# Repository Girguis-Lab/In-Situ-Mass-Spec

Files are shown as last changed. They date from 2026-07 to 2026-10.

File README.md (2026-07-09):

# In-Situ Mass Spectrometer V3

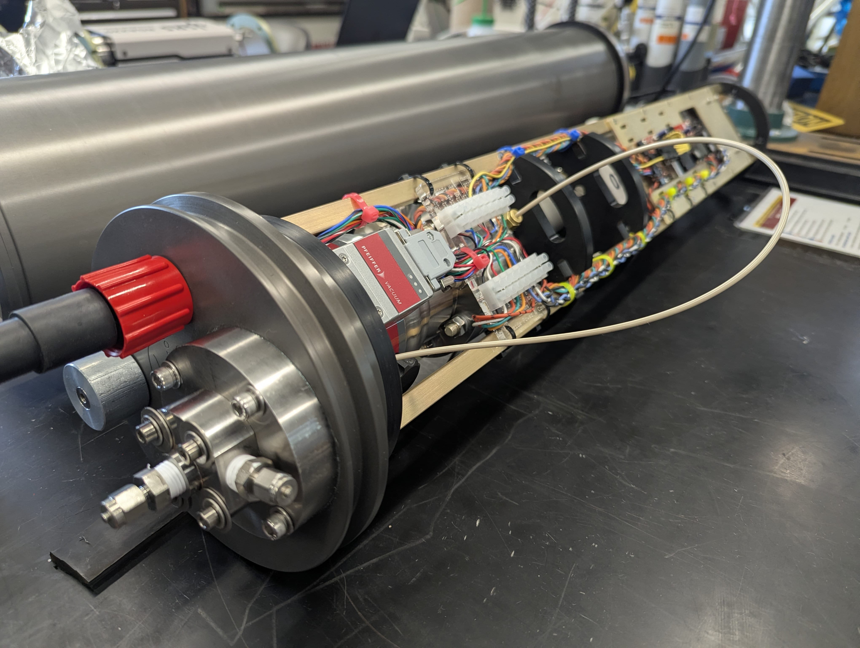
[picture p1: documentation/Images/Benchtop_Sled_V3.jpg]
Benchtop_Sled_V3


*__This repository contains the documentation and code for fabricating and operating version 3 of the Girguis Lab In-Situ Mass Spectrometer.__*

The In-Situ Mass Spectrometer (ISMS) is an open source biogeochemistry instrument for studying how disolved gases and volatile compounds influence ecosystems and processes in the ocean depths. It is designed as a membrane inlet mass spectrometer based on a commercially available quadrupole mass spectrometer. The ISMS is capable of detecting and quantifying volatiles up to 200 daltons at depths down to 4,500 m.

## Repository Organization:

* / [documentation](./documentation/)
</br>All documentation lives in this folder.

    * / [Operation](./documentation/Operation/README.md):</br>
    Operation instructions for using ISMSs in the field and in the lab.

    * / [Fabrication](./documentation/Fabrication/README.md):</br>
    Fabrication instructions to create new ISMSs including BOMs, PCB layouts, CAD designs, and engineering drawings

    * / [Calibration & Testing](<./documentation/Calibration & Testing/README.md>):</br>
    Methods for calibration and testing of the ISMS

* / [src](./src):</br>
The code that runs on the ATMEL microcontroller inside the ISMS lives in the /src folder as well as the /lib and /test folders.

## Contributing

The Girguis Lab is an open-source/open-design facility. We strongly believe that an “open source” approach to disseminating technologies enables more rapid discovery and more efficient use of our community’s limited financial resources. When partnering with commercial entities, we make every effort to encourage “open source” approaches to development, and to ensure that any co-developed technologies are—at the very least—available to academic scientists at a reasonable price.
Contributions and pull requests are welcome, however for major changes we seggest you to fork the repo and make your own version. Reach out to us if your group is building or redesigning an ISMS

## License
TODO - Add license
Please reach out to us at girguislab@oeb.harvard.edu with any questions!

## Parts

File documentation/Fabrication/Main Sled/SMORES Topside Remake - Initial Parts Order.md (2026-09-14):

## SMORES Topside Remake - Initial Parts Order:

2x https://www.adafruit.com/product/3055

3x https://www.amazon.com/Serial-Converter-Adapter-Supports-Windows/dp/B076WVFXN8

2x https://www.amazon.com/uxcell-Waterproof-Connector-Plastic-9mm-17mm/dp/B07ZMYQ3S3?th=1

2x https://www.amazon.com/Kingston-Canvas-256GB-microSD-SDCG4/dp/B0F29ZKKRC?th=1

1x https://www.amazon.com/QIANRENON-Charging-Adapter-Connector-480Mbps/dp/B0CRVH7JRD?th=1

1x https://www.amazon.com/Duttek-Shaped-Adapter-Extender-Indicator/dp/B0C69687M6?th=1

1x https://www.amazon.com/PlusRoc-Waterproof-Converter-Raspberry-Cellphone/dp/B0FD735LFG

1x https://www.amazon.com/Socket-Screws-Stainless-Thread-Spanner/dp/B0GHYBJ7ZK/

1x https://www.amazon.com/MroMax-M2-5x0-45mm-Stainless-Self-Locking-Insert/dp/B07YV96P2Y/

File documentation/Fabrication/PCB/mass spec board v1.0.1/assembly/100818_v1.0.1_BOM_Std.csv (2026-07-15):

Quantity | Designators | Package | Value | MPN | Manufacturer
18 | C1, C4, C6, C7, C8, C9, C10, C11, C44, C45, C46, C47, C48, C50, C51, C52, C53, C54 | CAPC2012 (0805) | 0.1μF | CL21B104KBCNNNC | Samsung Electro-Mechanics
3 | C2, C3, C12 | CAPC2012 (0805) | 22pF | C0805C220J5GAC7800 | KEMET
2 | C5, C35 | CAPC2012 (0805) | 1μF | CL21B105KBFNNNG | Samsung Electro-Mechanics
1 | C16 | CAPPRD500W80D1250H1400 | 330μF | URZ1H331MHD | Nichicon
2 | C17, C20 | CAPPRD500W80D1250H1400 | 220μF | URS1J221MHD1TO | Nichicon
1 | C18 | CAPC3216 (1206) | 0.1μF | CL31B104KEHSFNE | Samsung Electro-Mechanics
1 | C24 | CAPC2012 (0805) | 0.1μF | CL31B104KEHSFNE | Samsung Electro-Mechanics
1 | C26 | CAPPRD200W50D500H700 | 47μF | 860020572006 | Würth Elektronik
2 | C29, C30 | CAPC2012 (0805) | 1μF | CGA4J3X7S2A105M125AE
1 | C33 | CAPC2012 (0805) | 2.2μF | CL21B225KAFNFNE | Samsung Electro-Mechanics
1 | C34 | CAPC2012 (0805) | 100pF | CL21C101JCANNNC | Samsung Electro-Mechanics
1 | C38 | CAPC3225 (1210) | 1μF | CL32B105KCJNNNE | Samsung Electro-Mechanics
1 | C43 | CAPPRD200W50D500H700 | 22μF | ECE-A1EKA220 | Panasonic Electronic Components
1 | C49 | CAPC2012 (0805) | 1μF | CL21B105KBFNNNG
1 | C56 | CAPPRD250W50D630H1100 | 22μF | ESK226M100AE3AA | KEMET
2 | D1, D2 | SOT23-3P95_230X110L50X40 |  | BAS21 | SMC Diode Solutions
1 | F1 | CAPC4532 (1812) |  | MF-MSMF050-2 | Bourns Inc.
1 | J1 | Microfit_3mm_TH_RA_2x5 |  | 43045-1000 | Molex
1 | J2 | SS-52300-001 |  | SS-52300-001 | Stewart Connector
1 | J3 | Microfit_3mm_TH_RA_1x2 |  | 43650-0200
1 | J4 | Microfit_3mm_TH_RA_1x3 |  | 43650-0300
1 | J5 | Microfit_3mm_TH_RA_1x4 |  | 43650-0400
1 | J6 | Microfit_3mm_TH_RA_2x2 |  | 43045-0400 | Molex
1 | J7 | Microfit_3mm_TH_RA_2x1 |  | 43045-0200
1 | J8 | Microfit_3mm_TH_RA_2x3 |  | 43045-0600 | Molex
2 | J9, J10 | Pin Header 2.54mm 2x03 ⌀1.0mm |  | M20-9980346 | Harwin
1 | J11 | Pin Header 2.54mm 1x06 ⌀1.0mm |  | 61300611121 | Würth Elektronik
1 | J12 | Picoblade_vert_TH_1x4_530470410 |  | 530470410 | Molex
1 | L1 | INDC2012 (0805) |  | MH2029-300Y | Bourns Inc.
1 | L3 | INDC2012 (0805) | 10μH | MLZ2012N100LT000 | TDK Corporation
2 | L6, L7 | INDC3225 (1210) | 0mH | RC1210JR-070RL | YAGEO
4 | L8, L9, L10, L11 | INDC2012 (0805) | 0mH | RC0805FR-070RL | YAGEO
5 | LED1, LED2, LED3, LED4, LED5 | LED_0603 |  | LTST-C191KGKT | Lite-On Inc.
3 | Q2, Q3, Q4 | SOT223-4P230_700X180L175X75T175X300 |  | DMP6023LE-13 | Diodes Incorporated
3 | Q5, Q6, Q7 | SOT23-3P95_230X110L50X40 |  | DMN63D8L-7
6 | R1, R8, R12, R18, R19, R20 | RESC2012 (0805) | 10kΩ | RC0805FR-1310KL | YAGEO
5 | R2, R3, R13, R32, R33 | RESC2012 (0805) | 300Ω | RC0805FR-13300RL | YAGEO
3 | R4, R5, R6 | RESC2012 (0805) | 1kΩ | RC0805FR-131KL | YAGEO
2 | R7, R14 | RESC2012 (0805) | 1MΩ | RC0805FR-131ML | YAGEO
4 | R9, R10, R22, R23 | RESC2012 (0805) | 22Ω | RC0805FR-1322RL | YAGEO
1 | R15 | RESC3216 (1206) | 583Ω | RN73H2BTTD5830F100 | KOA Speer Electronics, Inc.
1 | R25 | RESC2012 (0805) | 15kΩ | RC0805FR-1315KL | YAGEO
5 | R26, R28, R29, R30, R31 | RESC2012 (0805) | 0Ω | RC0805FR-070RL | YAGEO
2 | R34, R35 | RESC3225 (1210) | 0.001Ω | PMR25HZPFV1L00 | Rohm
1 | S1 | 6mm_tact_switch_TE |  | 1825910-6 | TE Connectivity ALCOSWITCH Switches
1 | U1 | TQFP50P1600X1600X100-100 |  | ATMEGA2560-16AU-ND | Microchip
1 | U2 | SO8_390_1 |  | THDV1450DR | THVD1450DR
1 | U3 | SOT23-5P95_280X145L60X40 | 5V | AP2210K-5.0TRG1
1 | U4 | RSDW60 |  | RSDW60G-24 | MEAN WELL USA Inc.
1 | U5 | i7C4W |  | I7C4W012A050V-003-R | TDK-Lambda
1 | U6 | TSSOP16P65_500X640X120L100X30 |  | SP3232EBEY-L/TR
1 | U7 | TSR 0.6WI |  | TSR 0.6-48120WI | Traco Power
1 | U8 | TQFP80P900X900X100-32 |  | ATMEGA16U2-AU | Microchip Technology
2 | U9, U10 | SOT23-6P95_280X145L60X40 |  | TXU0101DBVR | Texas Instruments
1 | X1 | HC49_SMT |  | J49SMH-C-G-G-K-16M0 | Jauch Quartz
1 | Y2 | CSTCE16M0V53-R0 | 16MHz | CSTCE16M0V53-R0 | Murata Electronics
2 | Z1, Z2 | CAPC1608 (0603) |  | CG0603MLC-05E | Bourns Inc.

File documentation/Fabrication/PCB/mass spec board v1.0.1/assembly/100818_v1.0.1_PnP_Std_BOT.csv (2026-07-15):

# Pick&Place Position Data File
#
# Project Name: 100818
# Project Version: v1.0.1
# Board Name: 100817
# Generation Software: LibrePCB 1.1.0
# Generation Date: 2024-09-10T10:23:42
# Unit: mm
# Rotation: Degrees CCW
# Board Side: Bottom
# Assembly Types: THT | SMT | THT+SMT | Fiducial | Other
Designator | Value | Device | Package | Position X | Position Y | Rotation | Side | Type
C5 | CL21B105KBFNNNG | Capacitor 2012 (0805) | CAPC2012 (0805) | 19.1516 | 12.5984 | 180.0 | Bottom | SMT
C6 | CL21B104KBCNNNC | Capacitor 2012 (0805) | CAPC2012 (0805) | 21.844 | 14.732 | 0.0 | Bottom | SMT
C8 | CL21B104KBCNNNC | Capacitor 2012 (0805) | CAPC2012 (0805) | 38.227 | 35.306 | 270.0 | Bottom | SMT
C9 | CL21B104KBCNNNC | Capacitor 2012 (0805) | CAPC2012 (0805) | 46.5074 | 44.7548 | 90.0 | Bottom | SMT
C10 | CL21B104KBCNNNC | Capacitor 2012 (0805) | CAPC2012 (0805) | 50.546 | 32.766 | 0.0 | Bottom | SMT
C18 | CL31B104KEHSFNE | Capacitor 3216 (1206) | CAPC3216 (1206) | 125.7554 | 34.4932 | 90.0 | Bottom | SMT
C24 | CL31B104KEHSFNE | Capacitor 2012 (0805) | CAPC2012 (0805) | 81.915 | 48.26 | 0.0 | Bottom | SMT
C29 | CGA4J3X7S2A105M125AE | Capacitor 2012 (0805) | CAPC2012 (0805) | 80.137 | 8.001 | 0.0 | Bottom | SMT
C30 | CGA4J3X7S2A105M125AE | Capacitor 2012 (0805) | CAPC2012 (0805) | 80.137 | 5.588 | 0.0 | Bottom | SMT
C33 | CL21B225KAFNFNE | Capacitor 2012 (0805) | CAPC2012 (0805) | 72.4154 | 12.939888 | 270.0 | Bottom | SMT
C34 | CL21C101JCANNNC | Capacitor 2012 (0805) | CAPC2012 (0805) | 74.9554 | 11.669888 | 0.0 | Bottom | SMT
C35 | CL21B105KBFNNNG | Capacitor 2012 (0805) | CAPC2012 (0805) | 71.7804 | 18.019888 | 90.0 | Bottom | SMT
C44 | CL21B104KBCNNNC | Capacitor 2012 (0805) | CAPC2012 (0805) | 158.530636 | 36.83 | 270.0 | Bottom | SMT
C45 | CL21B104KBCNNNC | Capacitor 2012 (0805) | CAPC2012 (0805) | 158.530636 | 33.655 | 270.0 | Bottom | SMT
C46 | CL21B104KBCNNNC | Capacitor 2012 (0805) | CAPC2012 (0805) | 154.720636 | 38.735 | 180.0 | Bottom | SMT
C47 | CL21B104KBCNNNC | Capacitor 2012 (0805) | CAPC2012 (0805) | 150.275636 | 38.735 | 0.0 | Bottom | SMT
C48 | CL21B104KBCNNNC | Capacitor 2012 (0805) | CAPC2012 (0805) | 147.100636 | 37.465 | 270.0 | Bottom | SMT
C50 | CL21B104KBCNNNC | Capacitor 2012 (0805) | CAPC2012 (0805) | 44.0563 | 40.6654 | 0.0 | Bottom | SMT
C51 | CL21B104KBCNNNC | Capacitor 2012 (0805) | CAPC2012 (0805) | 25.611666 | 46.736 | 270.0 | Bottom | SMT
C52 | CL21B104KBCNNNC | Capacitor 2012 (0805) | CAPC2012 (0805) | 32.596666 | 46.736 | 270.0 | Bottom | SMT
C53 | CL21B104KBCNNNC | Capacitor 2012 (0805) | CAPC2012 (0805) | 20.743332 | 40.005 | 90.0 | Bottom | SMT
C54 | CL21B104KBCNNNC | Capacitor 2012 (0805) | CAPC2012 (0805) | 13.123332 | 40.005 | 90.0 | Bottom | SMT
D1 | BAS21 | BAS21 | SOT23-3P95_230X110L50X40 | 34.798 | 2.667 | 90.0 | Bottom | SMT
L1 | MH2029-300Y | Inductor 2012 (0805) | INDC2012 (0805) | 40.132 | 9.906 | 270.0 | Bottom | SMT
L8 | RC0805FR-070RL | Inductor 2012 (0805) | INDC2012 (0805) | 68.8594 | 20.686888 | 0.0 | Bottom | SMT
L9 | RC0805FR-070RL | Inductor 2012 (0805) | INDC2012 (0805) | 71.7804 | 21.194888 | 270.0 | Bottom | SMT
L10 | RC0805FR-070RL | Inductor 2012 (0805) | INDC2012 (0805) | 58.928 | 13.97 | 0.0 | Bottom | SMT
L11 | RC0805FR-070RL | Inductor 2012 (0805) | INDC2012 (0805) | 46.736 | 10.541 | 270.0 | Bottom | SMT
Q5 | DMN63D8L-7 | DMN63D8L-7 | SOT23-3P95_230X110L50X40 | 54.3052 | 24.0792 | 0.0 | Bottom | SMT
Q6 | DMN63D8L-7 | DMN63D8L-7 | SOT23-3P95_230X110L50X40 | 18.669 | 36.068 | 90.0 | Bottom | SMT
R1 | RC0805FR-1310KL | Resistor 2012 (0805) | RESC2012 (0805) | 21.463 | 36.195 | 90.0 | Bottom | SMT
R4 | RC0805FR-131KL | Resistor 2012 (0805) | RESC2012 (0805) | 14.097 | 24.892 | 180.0 | Bottom | SMT
R5 | RC0805FR-131KL | Resistor 2012 (0805) | RESC2012 (0805) | 14.097 | 22.352 | 180.0 | Bottom | SMT
R8 | RC0805FR-1310KL | Resistor 2012 (0805) | RESC2012 (0805) | 34.798 | 5.842 | 0.0 | Bottom | SMT
R15 | RN73H2BTTD5830F100 | Resistor 3216 (1206) | RESC3216 (1206) | 130.8862 | 37.973 | 270.0 | Bottom | SMT
R18 | RC0805FR-1310KL | Resistor 2012 (0805) | RESC2012 (0805) | 56.2864 | 20.574 | 90.0 | Bottom | SMT
R19 | RC0805FR-1310KL | Resistor 2012 (0805) | RESC2012 (0805) | 54.3814 | 20.574 | 270.0 | Bottom | SMT
R22 | RC0805FR-1322RL | Resistor 2012 (0805) | RESC2012 (0805) | 147.100636 | 34.925 | 0.0 | Bottom | SMT
R23 | RC0805FR-1322RL | Resistor 2012 (0805) | RESC2012 (0805) | 146.465636 | 33.02 | 0.0 | Bottom | SMT
R28 | RC0805FR-070RL | Resistor 2012 (0805) | RESC2012 (0805) | 145.830636 | 29.21 | 180.0 | Bottom | SMT
R29 | RC0805FR-070RL | Resistor 2012 (0805) | RESC2012 (0805) | 145.830636 | 31.115 | 180.0 | Bottom | SMT
R30 | RC0805FR-070RL | Resistor 2012 (0805) | RESC2012 (0805) | 51.6255 | 38.1 | 90.0 | Bottom | SMT
R31 | RC0805FR-070RL | Resistor 2012 (0805) | RESC2012 (0805) | 46.5455 | 32.766 | 180.0 | Bottom | SMT
U2 | THDV1450DR | THVD1450DR | SO8_390_1 | 46.4185 | 37.084 | 0.0 | Bottom | SMT
U3 | AP2210K-5.0TRG1 | AP2210K-5.0TRG1 | SOT23-5P95_280X145L60X40 | 74.9554 | 15.479888 | 270.0 | Bottom | SMT
U6 | SP3232EBEY-L/TR | SP3232EBEY-L/TR | TSSOP16P65_500X640X120L100X30 | 152.815636 | 34.29 | 0.0 | Bottom | SMT
U9 | TXU0101DBVR | TXU0101DBVR | SOT23-6P95_280X145L60X40 | 29.421666 | 46.101 | 0.0 | Bottom | SMT
U10 | TXU0101DBVR | TXU0101DBVR | SOT23-6P95_280X145L60X40 | 16.933332 | 40.64 | 180.0 | Bottom | SMT
Z1 | CG0603MLC-05E | Varistor_0603 | CAPC1608 (0603) | 34.163 | 12.192 | 90.0 | Bottom | SMT
Z2 | CG0603MLC-05E | Varistor_0603 | CAPC1608 (0603) | 34.163 | 15.367 | 270.0 | Bottom | SMT

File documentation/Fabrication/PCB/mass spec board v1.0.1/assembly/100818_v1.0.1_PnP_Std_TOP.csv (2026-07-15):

# Pick&Place Position Data File
#
# Project Name: 100818
# Project Version: v1.0.1
# Board Name: 100817
# Generation Software: LibrePCB 1.1.0
# Generation Date: 2024-09-10T10:23:42
# Unit: mm
# Rotation: Degrees CCW
# Board Side: Top
# Assembly Types: THT | SMT | THT+SMT | Fiducial | Other
Designator | Value | Device | Package | Position X | Position Y | Rotation | Side | Type
C1 | CL21B104KBCNNNC | Capacitor 2012 (0805) | CAPC2012 (0805) | 20.5486 | 27.559 | 0.0 | Top | SMT
C2 | C0805C220J5GAC7800 | Capacitor 2012 (0805) | CAPC2012 (0805) | 23.3426 | 25.1206 | 180.0 | Top | SMT
C3 | C0805C220J5GAC7800 | Capacitor 2012 (0805) | CAPC2012 (0805) | 16.8402 | 25.1968 | 0.0 | Top | SMT
C4 | CL21B104KBCNNNC | Capacitor 2012 (0805) | CAPC2012 (0805) | 30.1244 | 20.193 | 180.0 | Top | SMT
C7 | CL21B104KBCNNNC | Capacitor 2012 (0805) | CAPC2012 (0805) | 37.592 | 44.323 | 0.0 | Top | SMT
C11 | CL21B104KBCNNNC | Capacitor 2012 (0805) | CAPC2012 (0805) | 40.6146 | 47.0916 | 0.0 | Top | SMT
C12 | C0805C220J5GAC7800 | Capacitor 2012 (0805) | CAPC2012 (0805) | 26.162 | 27.94 | 180.0 | Top | SMT
C16 | URZ1H331MHD | Capacitor Radial ⌀12.5x14/5.0mm | CAPPRD500W80D1250H1400 | 99.8982 | 9.7028 | 0.0 | Top | THT
C17 | URS1J221MHD1TO | Capacitor Radial ⌀12.5x14/5.0mm | CAPPRD500W80D1250H1400 | 156.21 | 11.0236 | 0.0 | Top | THT
C20 | URS1J221MHD1TO | Capacitor Radial ⌀12.5x14/5.0mm | CAPPRD500W80D1250H1400 | 156.4386 | 26.7716 | 0.0 | Top | THT
C26 | 860020572006 | Capacitor Radial ⌀5.0x7.0/2.0mm | CAPPRD200W50D500H700 | 59.182 | 47.0916 | 90.0 | Top | THT
C38 | CL32B105KCJNNNE | Capacitor 3225 (1210) | CAPC3225 (1210) | 54.737 | 18.288 | 0.0 | Top | SMT
C43 | ECE-A1EKA220 | Capacitor Radial ⌀5.0x7.0/2.0mm | CAPPRD200W50D500H700 | 46.482 | 14.478 | 90.0 | Top | THT
C49 | CL21B105KBFNNNG | Capacitor 2012 (0805) | CAPC2012 (0805) | 31.75 | 39.37 | 0.0 | Top | SMT
C56 | ESK226M100AE3AA | Capacitor Radial ⌀6.3x11.0/2.5mm | CAPPRD250W50D630H1100 | 128.143 | 39.243 | 90.0 | Top | THT
D2 | BAS21 | BAS21 | SOT23-3P95_230X110L50X40 | 20.32 | 30.48 | 180.0 | Top | SMT
F1 | MF-MSMF050-2 | Polyfuse_1812 | CAPC4532 (1812) | 27.305 | 17.018 | 180.0 | Top | SMT
J1 | 43045-1000 | Microfit_3mm_TH_RA_2x5_43045-1000 | Microfit_3mm_TH_RA_2x5 | 168.91 | 16.51 | 90.0 | Top | THT
J2 | SS-52300-001 | SS-52300-001 | SS-52300-001 | 37.084 | 13.97 | 0.0 | Top | THT
J3 | 43650-0200 | Microfit_3mm_TH_RA_1x2_43650-0200 | Microfit_3mm_TH_RA_1x2 | 8.89 | 5.08 | 270.0 | Top | THT
J4 | 43650-0300 | Microfit_3mm_TH_RA_1x3_43650-0300 | Microfit_3mm_TH_RA_1x3 | 8.89 | 17.145 | 270.0 | Top | THT
J5 | 43650-0400 | Microfit_3mm_TH_RA_1x4_43650-0400 | Microfit_3mm_TH_RA_1x4 | 8.89 | 42.545 | 270.0 | Top | THT
J6 | 43045-0400 | Microfit_3mm_TH_RA_2x2_43045-0400 | Microfit_3mm_TH_RA_2x2 | 8.89 | 29.21 | 270.0 | Top | THT
J7 | 43045-0200 | Microfit_3mm_TH_RA_2x1_43045-0200 | Microfit_3mm_TH_RA_2x1 | 168.91 | 43.18 | 90.0 | Top | THT
J8 | 43045-0600 | Microfit_3mm_TH_RA_2x3_43045-0600 | Microfit_3mm_TH_RA_2x3 | 168.91 | 32.639 | 90.0 | Top | THT
J9 | M20-9980346 | Generic Pin Header 2.54mm 2x03 ⌀1.0mm | Pin Header 2.54mm 2x03 ⌀1.0mm | 26.416 | 5.08 | 0.0 | Top | THT
J10 | M20-9980346 | Generic Pin Header 2.54mm 2x03 ⌀1.0mm | Pin Header 2.54mm 2x03 ⌀1.0mm | 31.496 | 29.972 | 0.0 | Top | THT
J11 | 61300611121 | Generic Pin Header 2.54mm 1x06 ⌀1.0mm | Pin Header 2.54mm 1x06 ⌀1.0mm | 60.0456 | 35.6108 | 0.0 | Top | THT
J12 | 530470410 | Molex_Picoblade_1x4_VERT_TH_530470410 | Picoblade_vert_TH_1x4_530470410 | 47.5742 | 21.1582 | 270.0 | Top | THT
L3 | MLZ2012N100LT000 | Inductor 2012 (0805) | INDC2012 (0805) | 37.465 | 46.736 | 0.0 | Top | SMT
L6 | RC1210JR-070RL | Inductor 3225 (1210) | INDC3225 (1210) | 55.8292 | 38.2778 | 0.0 | Top | SMT
L7 | RC1210JR-070RL | Inductor 3225 (1210) | INDC3225 (1210) | 89.789 | 8.509 | 270.0 | Top | SMT
LED1 | LTST-C191KGKT | LED_0603 | LED_0603 | 12.7 | 14.605 | 0.0 | Top | SMT
LED2 | LTST-C191KGKT | LED_0603 | LED_0603 | 12.7 | 15.875 | 0.0 | Top | SMT
LED3 | LTST-C191KGKT | LED_0603 | LED_0603 | 51.2318 | 25.157288 | 90.0 | Top | SMT
LED4 | LTST-C191KGKT | LED_0603 | LED_0603 | 44.8056 | 45.0342 | 90.0 | Top | SMT
LED5 | LTST-C191KGKT | LED_0603 | LED_0603 | 43.561 | 45.085 | 90.0 | Top | SMT
Q2 | DMP6023LE-13 | DMP6023LE-13 | SOT223-4P230_700X180L175X75T175X300 | 16.129 | 36.576 | 180.0 | Top | SMT
Q3 | DMP6023LE-13 | DMP6023LE-13 | SOT223-4P230_700X180L175X75T175X300 | 24.384 | 41.783 | 180.0 | Top | SMT
Q4 | DMP6023LE-13 | DMP6023LE-13 | SOT223-4P230_700X180L175X75T175X300 | 56.134 | 24.003 | 180.0 | Top | SMT
Q7 | DMN63D8L-7 | DMN63D8L-7 | SOT23-3P95_230X110L50X40 | 31.369 | 43.434 | 180.0 | Top | SMT
R2 | RC0805FR-13300RL | Resistor 2012 (0805) | RESC2012 (0805) | 12.065 | 12.065 | 90.0 | Top | SMT
R3 | RC0805FR-13300RL | Resistor 2012 (0805) | RESC2012 (0805) | 12.065 | 8.255 | 90.0 | Top | SMT
R6 | RC0805FR-131KL | Resistor 2012 (0805) | RESC2012 (0805) | 17.0434 | 28.7274 | 180.0 | Top | SMT
R7 | RC0805FR-131ML | Resistor 2012 (0805) | RESC2012 (0805) | 19.9644 | 25.1206 | 0.0 | Top | SMT
R9 | RC0805FR-1322RL | Resistor 2012 (0805) | RESC2012 (0805) | 26.6192 | 12.2428 | 180.0 | Top | SMT
R10 | RC0805FR-1322RL | Resistor 2012 (0805) | RESC2012 (0805) | 26.6192 | 14.0462 | 180.0 | Top | SMT
R12 | RC0805FR-1310KL | Resistor 2012 (0805) | RESC2012 (0805) | 26.162 | 30.353 | 180.0 | Top | SMT
R13 | RC0805FR-13300RL | Resistor 2012 (0805) | RESC2012 (0805) | 50.165 | 22.352 | 270.0 | Top | SMT
R14 | RC0805FR-131ML | Resistor 2012 (0805) | RESC2012 (0805) | 43.688 | 24.8412 | 90.0 | Top | SMT
R20 | RC0805FR-1310KL | Resistor 2012 (0805) | RESC2012 (0805) | 31.242 | 46.736 | 180.0 | Top | SMT
R25 | RC0805FR-1315KL | Resistor 2012 (0805) | RESC2012 (0805) | 31.75 | 36.83 | 0.0 | Top | SMT
R26 | RC0805FR-070RL | Resistor 2012 (0805) | RESC2012 (0805) | 35.687 | 24.511 | 180.0 | Top | SMT
R32 | RC0805FR-13300RL | Resistor 2012 (0805) | RESC2012 (0805) | 45.3898 | 48.006 | 270.0 | Top | SMT
R33 | RC0805FR-13300RL | Resistor 2012 (0805) | RESC2012 (0805) | 43.5102 | 48.006 | 270.0 | Top | SMT
R34 | PMR25HZPFV1L00 | Resistor 3225 (1210) | RESC3225 (1210) | 137.033 | 41.148 | 270.0 | Top | SMT
R35 | PMR25HZPFV1L00 | Resistor 3225 (1210) | RESC3225 (1210) | 93.98 | 43.815 | 90.0 | Top | SMT
S1 | 1825910-6 | 1825910-6 | 6mm_tact_switch_TE | 41.0464 | 20.066 | 90.0 | Top | THT
U1 | ATMEGA2560-16AU-ND | ATMEGA2560-16AU-ND | TQFP50P1600X1600X100-100 | 43.815 | 34.925 | 0.0 | Top | SMT
U4 | RSDW60G-24 | RSDW60G-24 | RSDW60 | 74.93 | 25.4 | 0.0 | Top | THT
U5 | I7C4W012A050V-003-R | I7C4W012A050V-003-R | i7C4W | 121.92 | 3.175 | 90.0 | Top | THT
U7 | TSR 0.6-48120WI | TSR 0.6-48120WI | TSR 0.6WI | 55.6514 | 10.3124 | 0.0 | Top | THT
U8 | ATMEGA16U2-AU | ATMEGA16U2-AU | TQFP80P900X900X100-32 | 19.05 | 13.335 | 270.0 | Top | SMT
X1 | J49SMH-C-G-G-K-16M0 | Crystal_HC49_SMT | HC49_SMT | 19.812 | 21.463 | 180.0 | Top | SMT
Y2 | CSTCE16M0V53-R0 | CSTCE16M0V53-R0 | CSTCE16M0V53-R0 | 41.148 | 25.273 | 180.0 | Top | SMT

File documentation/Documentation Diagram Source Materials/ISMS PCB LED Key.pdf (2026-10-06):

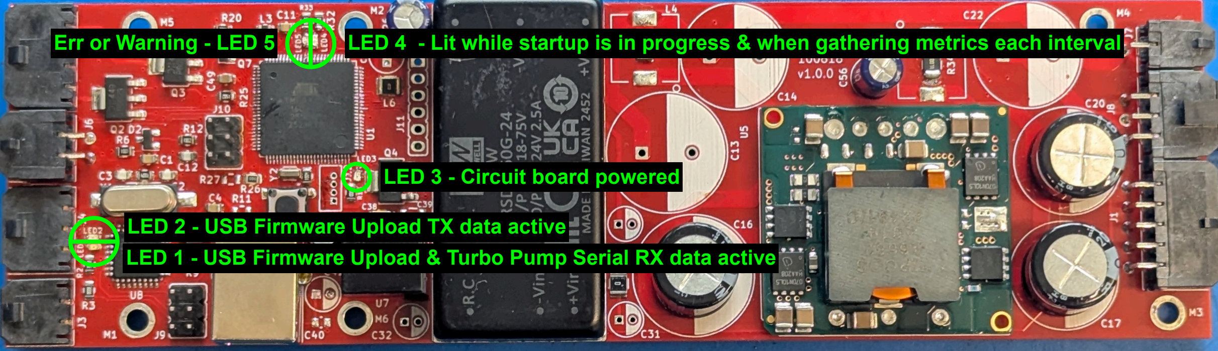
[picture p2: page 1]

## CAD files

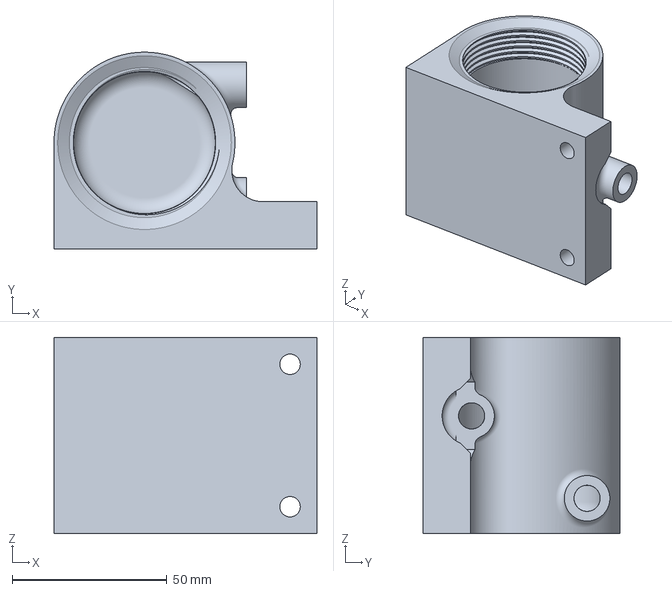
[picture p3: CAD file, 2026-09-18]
documentation/Fabrication/pH Sensor/3D Print Models/PyroScience AquapHOx FlowCell Attachment - Flow Cell Full.3mf
85.1 x 63.6 x 63.5 mm

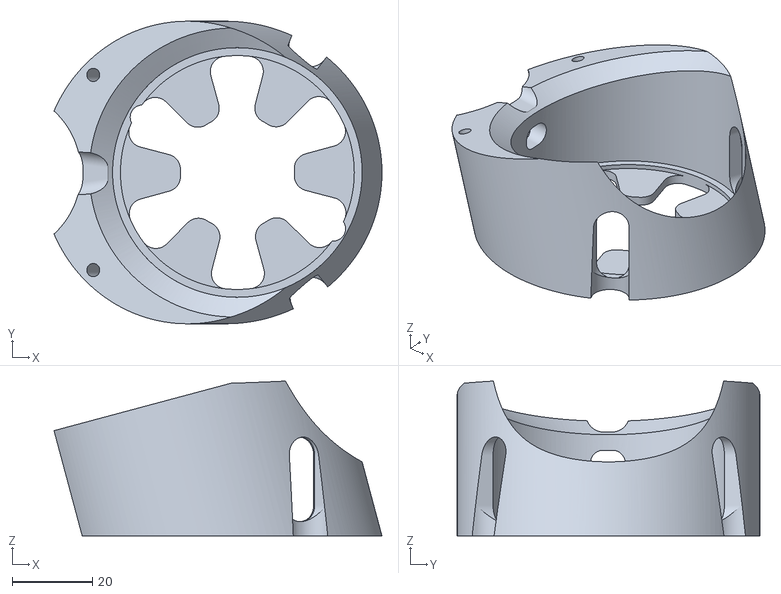
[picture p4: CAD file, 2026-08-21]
documentation/Fabrication/Fluid Pump/3D Print Models/Fluid Pump Mount - Pump Mount for BR 3- Housing.stl
81.5 x 75.2 x 38.5

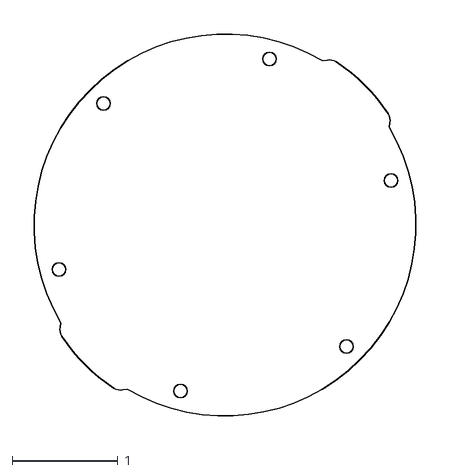
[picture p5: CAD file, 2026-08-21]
documentation/Fabrication/Fluid Pump/Laser Cut Designs/SHAPE REFERENCE ONLY - Diaphram Gasket - Buna-N Rubber Gasket.dxf
3.95 x 3.95

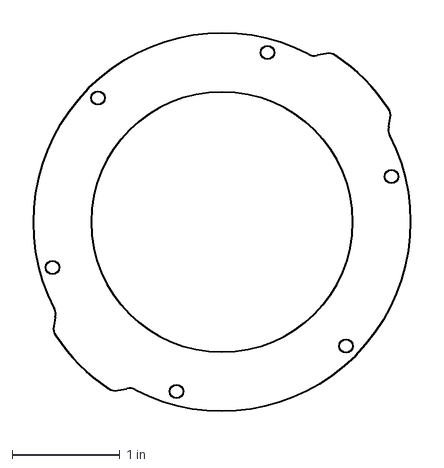
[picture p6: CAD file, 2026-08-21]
documentation/Fabrication/Fluid Pump/Laser Cut Designs/BR End Cap Plate W Diaphragm Opening.dxf
3.81 x 3.81 in

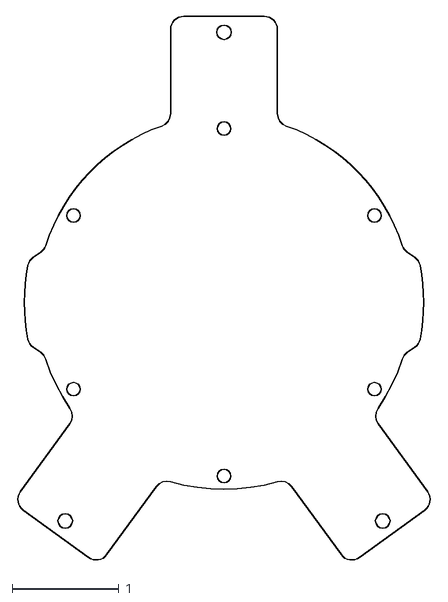
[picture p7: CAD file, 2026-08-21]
documentation/Fabrication/Fluid Pump/Laser Cut Designs/BR end cap drilling guide jig top plate.dxf
3.89 x 5.10

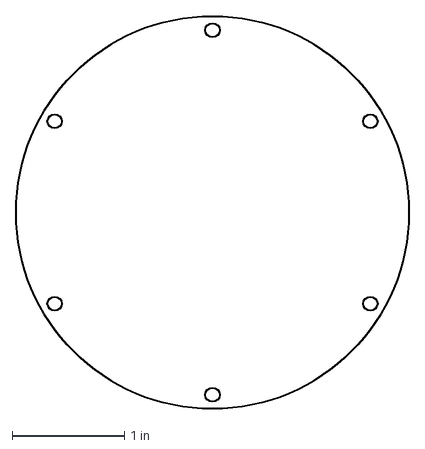
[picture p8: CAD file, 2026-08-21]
documentation/Fabrication/Fluid Pump/Laser Cut Designs/BR end cap drilling guide jig spacer plate.dxf
3.50 x 3.50 in

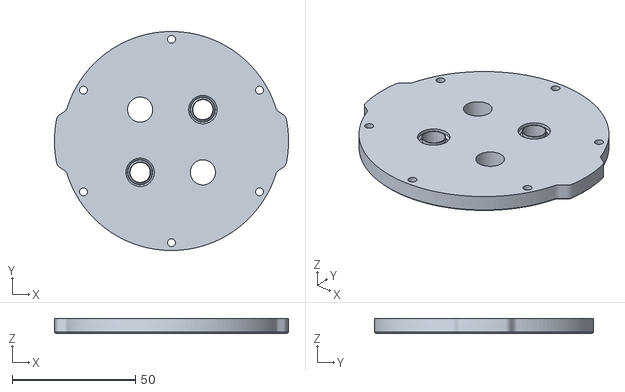
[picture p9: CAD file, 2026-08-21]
documentation/Fabrication/Fluid Pump/Laser Cut Designs/Customized_WTE3-M-END-CAP-4-HOLE-R1 - Fluid Pump End Cap plate W penetrator holes.stl
95.0 x 88.9 x 6.00

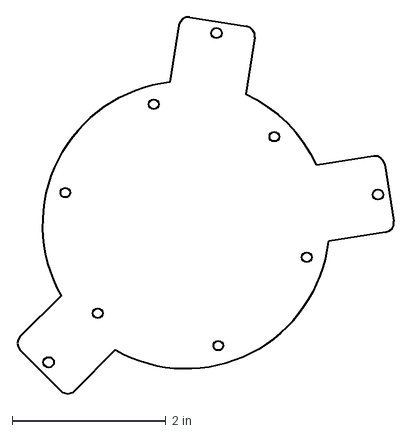
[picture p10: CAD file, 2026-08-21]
documentation/Fabrication/Fluid Pump/Laser Cut Designs/BR end cap drilling guide jig bottom plate.dxf
4.92 x 4.91 in

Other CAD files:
documentation/Fabrication/pH Sensor/3D Print Models/PyroScience AquapHOx FlowCell Attachment - Flow Cell Full.stl

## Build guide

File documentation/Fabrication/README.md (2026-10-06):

Work in progress... Stay tuned for updates!

Full Parts List: [Here](<../Documentation Diagram Source Materials/ISMS V3 Parts List.numbers>)

Recommended Build Order:
1. [PCB](./PCB/README.md)
2. [Vacuum System](<./Vacuum System/README.md>)
3. [Main Sled](<./Main Sled/README.md>)
4. [Wiring](<./Wiring/README.md>)
5. [Fluid Pump](<./Fluid Pump/README.md>)
6. [pH Sensor](<pH Sensor/README.md>)
7. [Sealing Housing](<Housing/README.md>)
7. [Vehicle Integration Guide](<ISMS V3 Vehicle Integration Guide.md>)

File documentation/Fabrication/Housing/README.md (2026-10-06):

# Housing Assembly

### Install Rear End Cap

1. Wipe away debris and old grease from sealing surfaces with a lint-free cloth.

2. Use Molykote 111 silicone grease to lightly grease the o-rings for the end cap (o-ring dash sizes #261 and #359) and install them in the grooves:<br/>
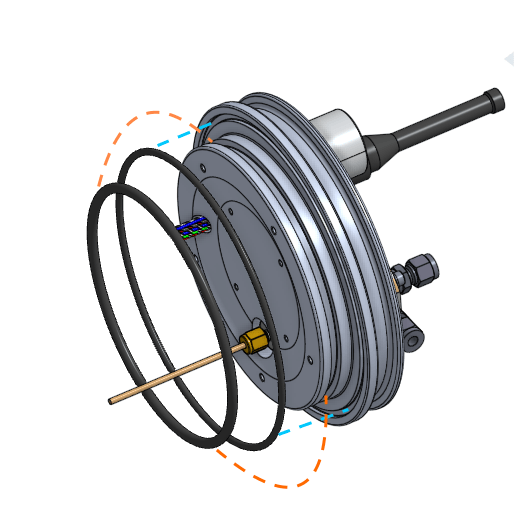
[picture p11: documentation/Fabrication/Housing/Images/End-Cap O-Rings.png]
O-Ring Placement


3. Hold the endcap up against the main enclosure<br/>
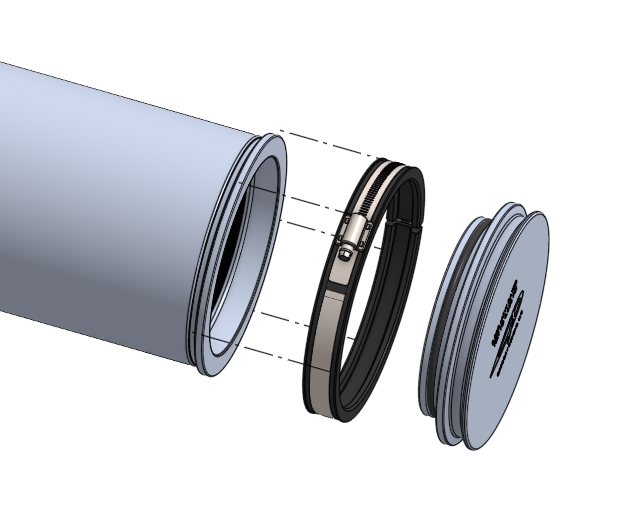
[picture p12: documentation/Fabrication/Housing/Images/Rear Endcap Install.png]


3.  Expand the black housing clamp slightly and install over the flange clamp protrusions, then install the hose clamp over that and tighten.

### Front Endcap Install

1. Unscrew the vent plug from the end cap using a hex key:<br/>
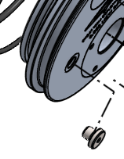
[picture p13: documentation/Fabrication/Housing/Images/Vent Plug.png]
Vent Plug


4. Slide chassis assembly along with main endcap into tube, making sure the rails don’t scratch the inner surfaces of the housing.<br/>
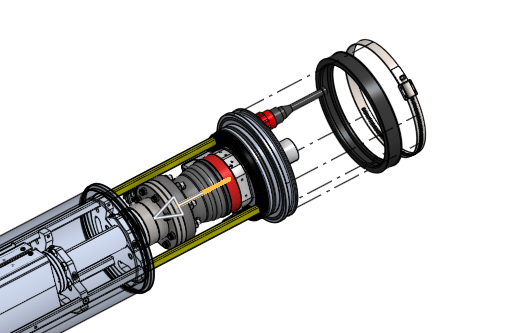
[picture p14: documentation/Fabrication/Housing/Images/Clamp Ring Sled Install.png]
Clamp Ring Sled Install


5. Add large desiccant packs to absorb the water vapor that will be ejected from the vacuum pumps into the housing as you go anywhere they will fit.

6. Turn the whole ISMS enclosure vertically onto the flat opposite end cap.

7. Press down firmly, making sure the face o-ring stays centered in its groove as it goes \- extra grease on that side may help keep it in the groove.

8. Expand the black housing clamp slightly and install over the flange clamp protrusions, then install the hose clamp over that and tighten: <br/>
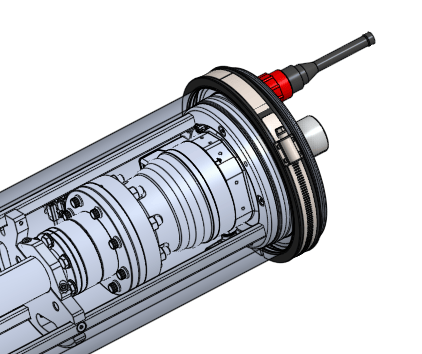
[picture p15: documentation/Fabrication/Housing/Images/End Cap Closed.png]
Housing Closed


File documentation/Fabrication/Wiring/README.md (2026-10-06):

## Internal Wiring

### Cut Wires

Cut the following sections of 24 AWG Silicone wire (or other flexible, stranded wire):

**RGA Power Wires** - 6 inches (5.5in once twisted together)

*Connectors: 2pin vertical female Micro-fit 3.0 | 5.5mm x 2.1mm center+ locking barrel plug  (Provided w RGA)*

- Black
- Red

**RGA Serial Wires** - 26.5 inches (24.75in once twisted together)

*Connector: Male DB9 with hood - fake handshake wiring will be added*

- Black
- Blue
- White with Black stripe

**Roughing Pump Power Wires** - 14.5 inches (13.5in once twisted together)

- Red
- Black

**Turbo Pump Power & Serial Wires** - 17.75 inches (16.5in once twisted together)

- Red
- Black
- Brown
- Orange

**Topside Power & Serial Wires** - 28.4 inches (26.5in once twisted together)

- Black
- White
- Red
- Green
- Orange
- Red with Black stripe

**Fluid Pump Wires** - 13 inches (12.25in once twisted together)

- Green with Black stripe
- Orange with Black stripe
- Blue with Black stripe
- Black with White stripe

**Fluid Pump Direction Control Add-on Wires**

- Yellow - 13.5 inches (not twisted>)
- 6x yellow solid core wire - 1.75 inches

**pH probe wires** (optional) - 15.5 inches (14.5in once twisted together)

- Red with White stripe
- Green with White stripe
- Blue with White Stripe
- Black with Red Stripe

Twist or braid wires into cables so they form nice bundles like so - a shortcut to do this is to leave some extra wire at one end to insert in the jaws of a power drill on low speed, with the other end clamped, then cut off the part that got mangled in the jaws once twisted sufficiently. Best practice would be to center the ground conductor in the larger cable bundles, but this is not necessary for the short distances involved:

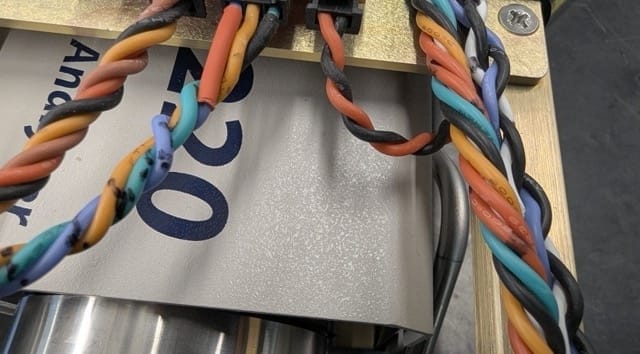
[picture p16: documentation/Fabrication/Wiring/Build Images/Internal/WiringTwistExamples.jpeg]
WiringTwistExamples


### Adding Connectors

All connectors on either end of the Main PCB are molex Micro-fit 3.0 female connectors consisting of pin sockets which must be crimped and inserted into connector bodies of various pin count.

Crimping molex pins and sockets is fairly simple, but there are many things to keep in mind to ensure a solid connection, with proper strip length, that doesn't bend parts of the connnector that should stay straight. Watch these videos to learn how to crimp: https://www.youtube.com/watch?v=pTJ77xNArZA & https://www.youtube.com/watch?v=2CHQWd-844Y and keep in mind the molex guidelines on page 17 of this guide https://tools.molex.com/pdm_docs/ats/TM-638000029.pdf

Gold plated connectors are recommended as these have slightly more durability. Even still keep plugging/unplugging to a minimum - many connectors are only rated to 10's of plug/unplug cycles.

#### Main PCB Connections

Create pigtails (connector at one end with bare ends at the other) for each used connector on the PCB.

Follow the wire color pin order to make each connector pigtail. Color coding is shown in the [ISMS PCB Pinouts Annotated](<./Build Images/Internal/ISMS PCB Pinouts Annotated.png>) file shown below. The wire color coding for each connector pin is shown below the label in the corresponding pin location as a line.

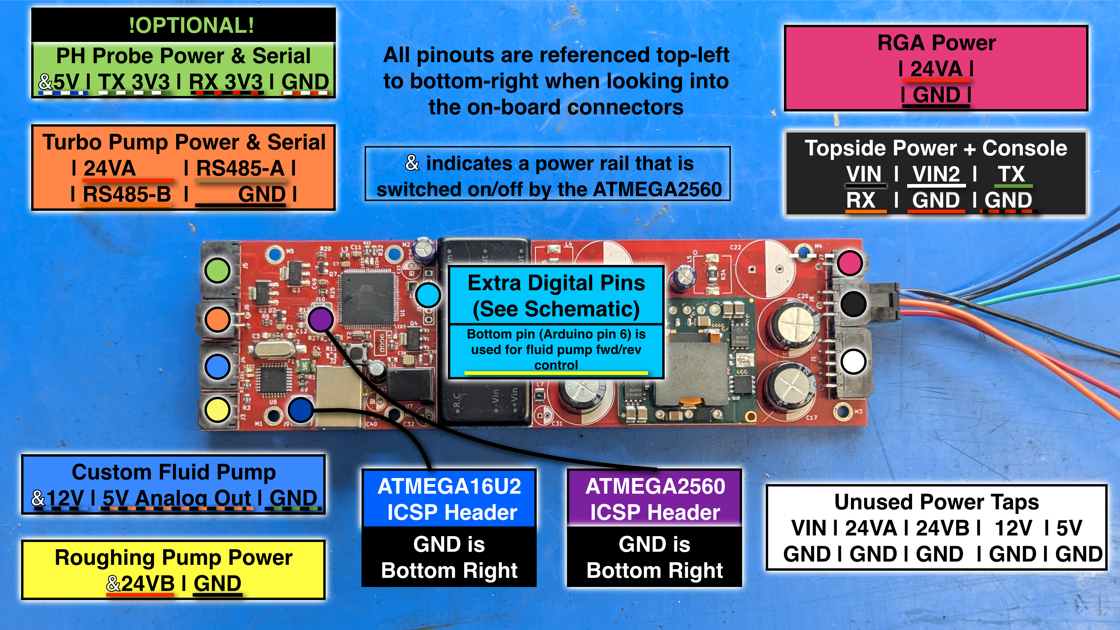
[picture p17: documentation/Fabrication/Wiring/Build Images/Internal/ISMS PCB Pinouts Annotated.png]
ISMS PCB Pinouts Annotated


#####

##### pH Probe Connection (UNUSED):

	4x1 PIN female Micro-fit 3.0

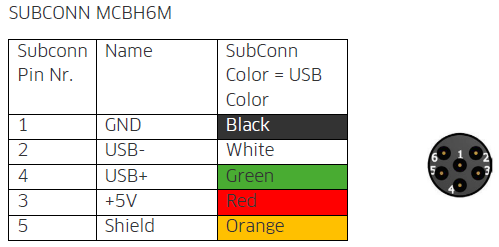
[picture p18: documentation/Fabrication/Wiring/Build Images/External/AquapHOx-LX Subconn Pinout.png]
AquapHOx-LX Subconn Pinout
Currently the pH probe is not connected because we are using a standalone pH logger (PyroScience AquapHOx-LX) that doesn't need power or data. Theoretically realtime data can be got from the AquapHOx-LX, but it requires a USB host intermediary like a raspberry pi to read the serial data (format found in the [protocol docs]) if wired per the USB output wires shown here: 

##### RGA Power:

	2x1 PIN vertical female Micro-fit 3.0

##### Turbo Pump Power & Serial Wires:

	2x2 PIN female Micro-fit 3.0

##### Topside Power + Console:

	 3x2 PIN female Micro-fit 3.0

##### Custom Fluid Pump:

	3x1 PIN female Micro-fit 3.0

##### Roughing Pump Power:

	2x1 horizontal female Micro-fit 3.0

##### Extra Digital Pins

	1x6 PIN male & female Micro-fit 3.0 connector

(used for adding direction forward/reverse control to Fluid Pump):

Solder 6 short connections from the PCB to a free-floating 6 pin male Micro-fit 3.0 connector and another to the yellow wire on pin 6 as shown here at the bottom of the photo. The 6 pin setup is to allow future expansion and structural integrity.

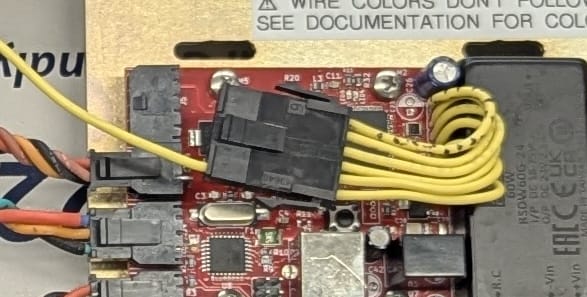
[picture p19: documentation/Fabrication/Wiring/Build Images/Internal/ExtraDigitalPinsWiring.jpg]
ExtraDigitalPinsWiring


##### Extra Power Taps (UNUSED):

 5x2 PIN female Micro-fit 3.0

##### ICSP Headers (X2, BOOTLOADER TROUBLESHOOTING ONLY):

3x2 standard 2.54mm pitch pin header (not Molex>)

#### Other Connectors

##### RGA Power Plug

- **Side A (Already Done):** 2pin vertical female Micro-fit 3.0

- **Side B:** 5.5mm x 2.1mm center+ locking barrel plug  (Provided w RGA)*

  - Solder connector like so: https://electronics.stackexchange.com/questions/77671/how-to-solder-wires-on-to-this-power-barrel-plug. Use Heat shrink to insulate inner contact. When installing, the tabs on this barrel plug twist lock into the RGA body - Do not force it in or out!

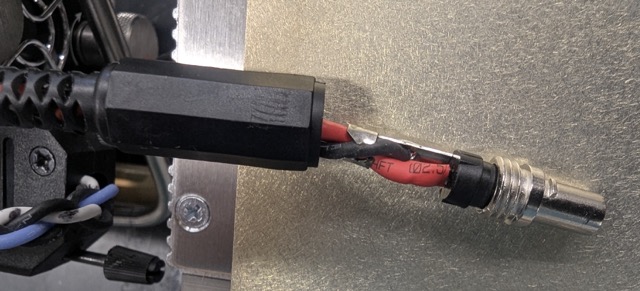
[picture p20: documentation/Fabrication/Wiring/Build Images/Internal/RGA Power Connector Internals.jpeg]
RGA Power Connector Internals
  

##### RGA Serial Connection

Does not go through PCB, instead it goes directly to terminal block and out of main housing up tether or to vehicle

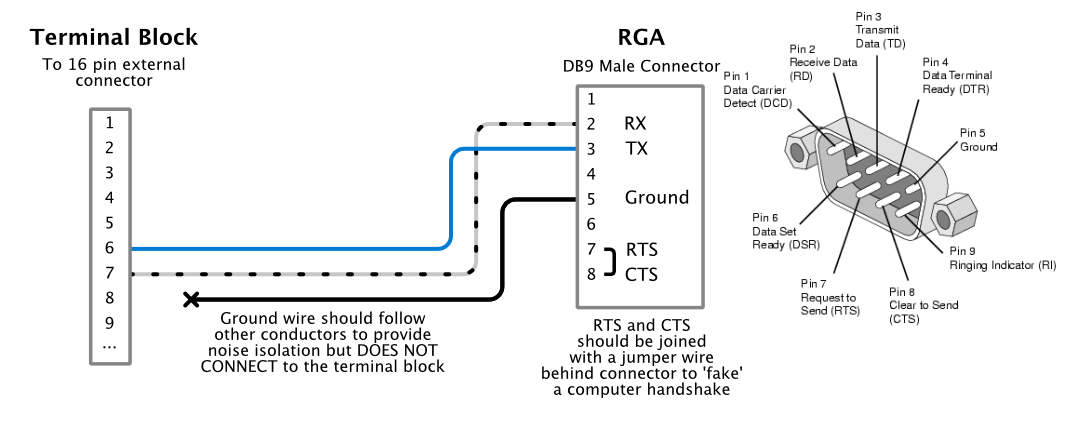
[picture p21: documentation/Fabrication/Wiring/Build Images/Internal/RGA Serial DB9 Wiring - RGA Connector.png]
RGA Serial DB9 Wiring - RGA Connector


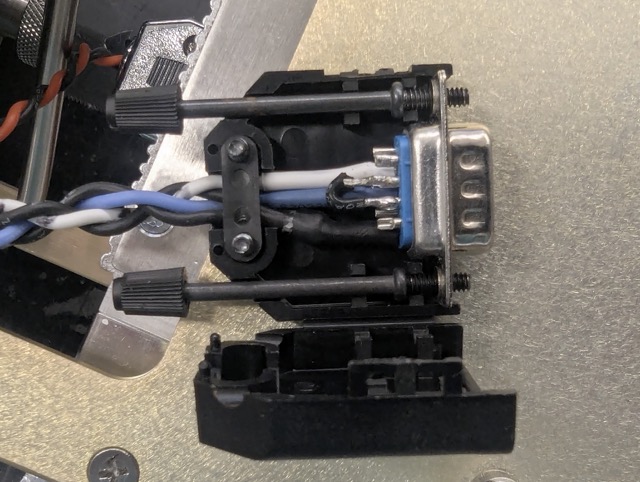
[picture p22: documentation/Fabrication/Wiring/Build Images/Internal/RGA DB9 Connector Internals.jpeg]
RGA DB9 Connector Internals


##### **Roughing Pump Power**

The roughing pump uses a male DB15 plug and also requires some jumpers behind the connector that tell the roughing pump to start up inmediately once power is supplied. See page 23 of the [roughing pump manual](<../../Operation/Component Manuals/Roughing Pump Manual pfeiffer_mvp_010_3_dc.pdf) for an explanation of this wiring.

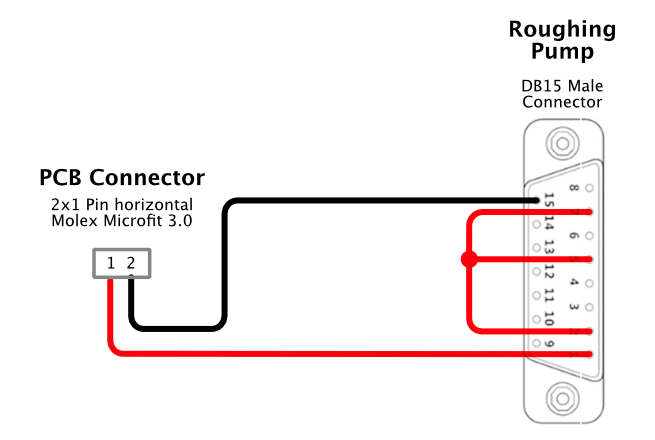
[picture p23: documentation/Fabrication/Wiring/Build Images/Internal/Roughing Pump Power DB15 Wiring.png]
Roughing Pump Power DB15 Wiring


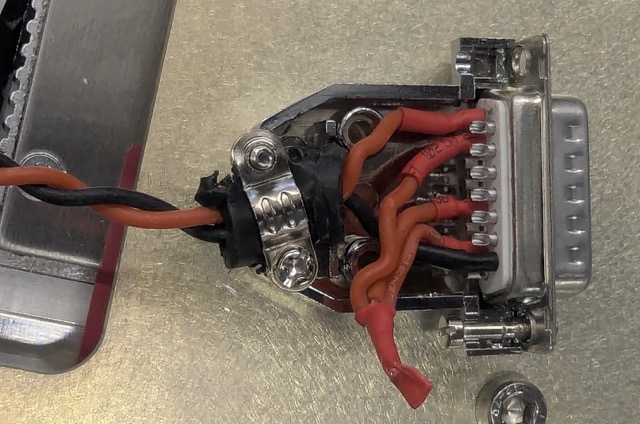
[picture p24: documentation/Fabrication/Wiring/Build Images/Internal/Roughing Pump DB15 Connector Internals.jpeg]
Roughing Pump DB15 Connector Internals


##### Turbo Pump Connector

The Turbo Pump connector is simpler but follows a similar pinout as the roughing pump. See the turbo pump TC80 controller manual page 18 for an explanation of pinout:   [Turbo Pump Control Unit Manual Pfeiffer-TC-80_Operating-Instructions.pdf](<../../Operation/Component Manuals/Turbo Pump Control Unit Manual Pfeiffer-TC-80_Operating-Instructions.pdf)

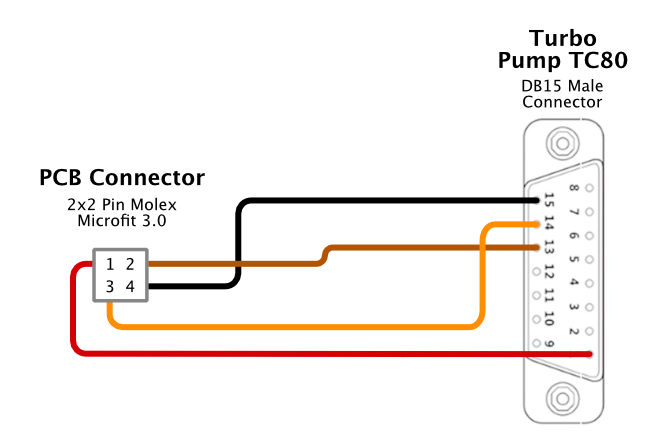
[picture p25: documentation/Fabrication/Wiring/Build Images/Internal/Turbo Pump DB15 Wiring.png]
Turbo Pump DB15 Wiring


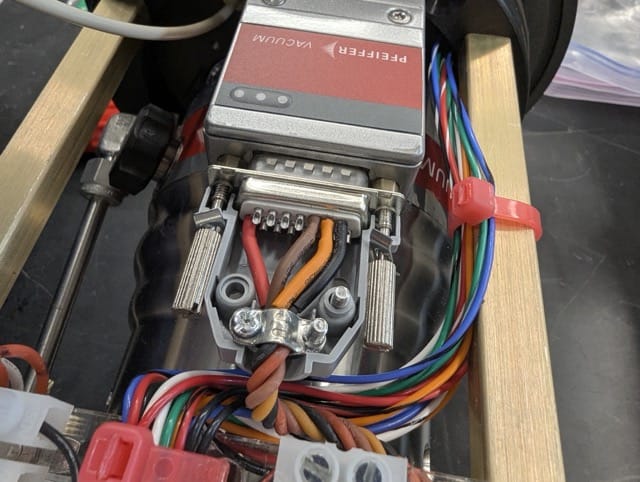
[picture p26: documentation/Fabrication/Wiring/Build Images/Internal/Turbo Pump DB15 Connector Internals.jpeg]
Turbo Pump DB15 Connector Internals


### Wire Routing

Recommended wiring routing layout using zipties

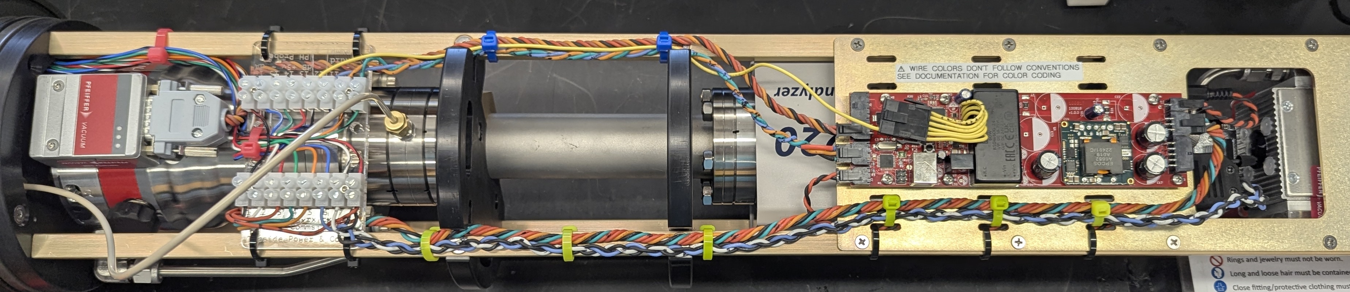
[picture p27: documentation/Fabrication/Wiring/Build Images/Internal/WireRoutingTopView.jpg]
WireRoutingTopView


Roughing pump power cable is tucked underneath lower rail and held with black zipties:

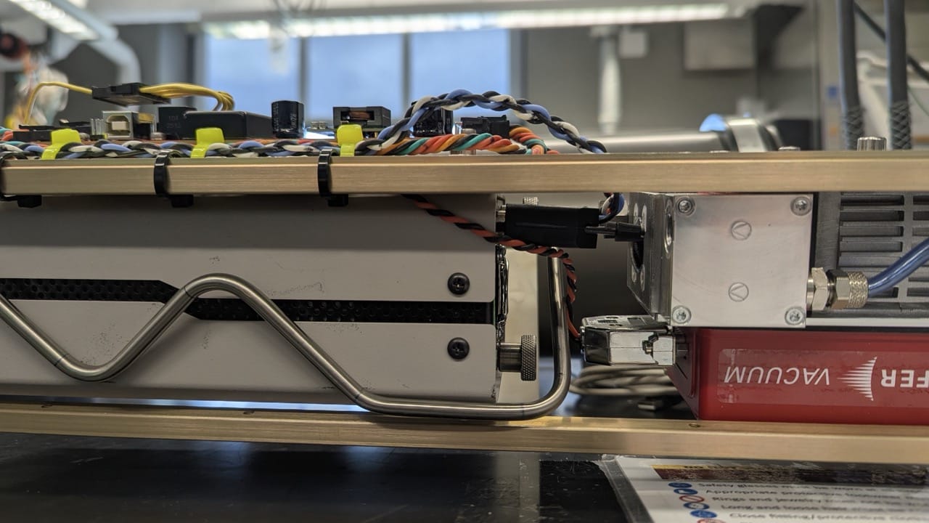
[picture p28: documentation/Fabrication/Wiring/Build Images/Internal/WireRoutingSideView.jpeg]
WireRoutingSideView


The terminal block plate sits over the turbo pump and connects the 16pin subconn external connection wires to the isms internals. The mounting plate should be laser cut & engraved from 1/4" thick accrylic using the file: [Terminal Block Mounting Plate Laser Cut.eps](<Laser Cut Designs/Terminal Block Mounting Plate Laser Cut.eps) Every wire from the 16 pin external connection matches the color of the corresponding wire internally except for the fluid pump forward/reverse wire, which is the only yellow wire in the system and connects to the black wire with white stripe in position 12 on the terminal blocks (and 16 pin subconn).

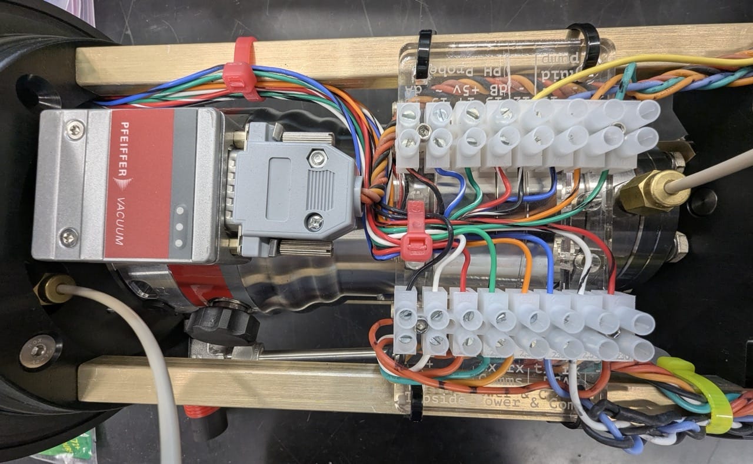
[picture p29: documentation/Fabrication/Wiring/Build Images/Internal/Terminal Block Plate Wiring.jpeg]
Terminal Block Plate Wiring


Note that the pH probe connections remain empty due to the afformentioned lack of need for power or communication with the aquapHOx LX pH logger. If a non-standalone pH probe is added in the future these wires can be used for that (or another accesory like a cryopump). They would connect to the pH probe power and serial plug on the PCB shown in [ISMS PCB Pinouts Annotated.png](<./Build Images/Internal/ISMS PCB Pinouts Annotated.png) (assuming the pH probe was 5v powered and used ttl serial communication>)

## Topside Wiring

For now we'll ignore the wiring in between the ISMS and focus on the connectors a topside operator or vechicle needs to power and communicate with the ISMS and onboard RGA. In the next section we'll connect those connectors to the actual ISMS for testing!

### Power plugs

We recommend using Molex Micro-fit connectors to connect to your power supplies for consistancy with the rest of the connectors inside the instrument however this is amenable to using whatever plug your power supply already comes with. Independent power supplies are recommended but not necessary.

### ISMS Main Comms Serial Plug

Topside Main Comms DB9 Wiring

The main comms of the ISMS talks to the onboard arduino-like chip and provides overall control and status of the instrument. When wiring this plug, leave loose ends in the colors shown noting that this plug acts as a "Null Modem" swapping RX and TX from the corresponding pins inside the ISMS to provide proper serial flow.

### RGA Comms Serial Plug

Topside RGA Comms DB9 Wiring

The RGA comms of the ISMS 'talks' directly to the onboard RGA providing the mass spectra and tuning of the RGA via the windows software (or python library). This plug requires some extra jumper wiring to "Fake" and handshake signal normally sent between the computer and RGA to keep them from talking over each other. In practice this fake handshake is sufficient as the windows software and RGA always follow a command-response format and so are never talking over each other anyway - this allows us to only require two signal wires to communicate with the RGA instead of 9. These jumper wires should fit into a plastic "Hood" on the back of the DB9 Connector to keep things tidy.

> [!NOTE]
>
> The RGA has an internal "Null Modem" wire switch and expects a "straight through" style serial cable, hence why there is no crossing of RX and TX wires between the bottom and topsides.

### Overall Topside/Operator Wiring

ISMS Recommended Topside Wiring

Shown in this diagram is the recommended overall wiring of the topside / operator side. No need to complete this now, refer to this diagram and table below if needed for correct wiring in the next section.

## External 'Octopus Cable' Wiring

The exterior of the ISMS has a 1in-3out "Octopus" style cable to connect the main housing various external components in a watertight manner. It is made by potting together several subconn connector pigtails. The subconn provided cable pigtails follow a consistant color to PIN number scheme. The wiring of this octopus cable can be figured out from [SubCon Octopus Cable Key.pdf](<./SubCon Octopus Cable Key.pdf>). The black cable in this system overview is the octopus cable:
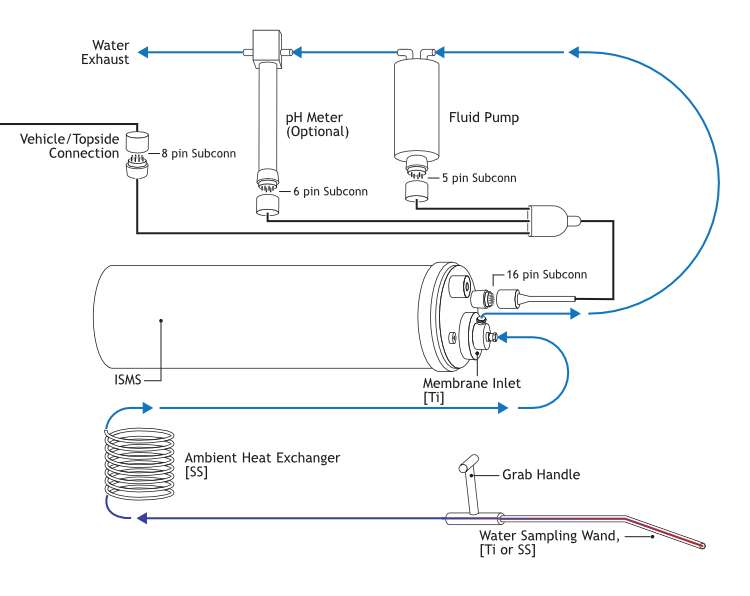
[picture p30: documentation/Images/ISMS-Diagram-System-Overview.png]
ISMS-Diagram-System-Overview
 

### Testing with quick connectors

We will be making a test wiring harness / octopus cable directly from the subconn 16 pin female pigtail. Start by stripping back 2 inches of the outer sheath using either techinique shown in [this guide](https://bluerobotics.com/learn/cable-stripping/) and also strip and twist each conductor about 1/4". Using [these connectors](https://www.digikey.com/en/products/detail/adafruit-industries-llc/5619/17506672) we can quickly make a harness to test what a full topside connection would be like, minus any other connectors between the topside/operator and ISMS and length of wire in-between.

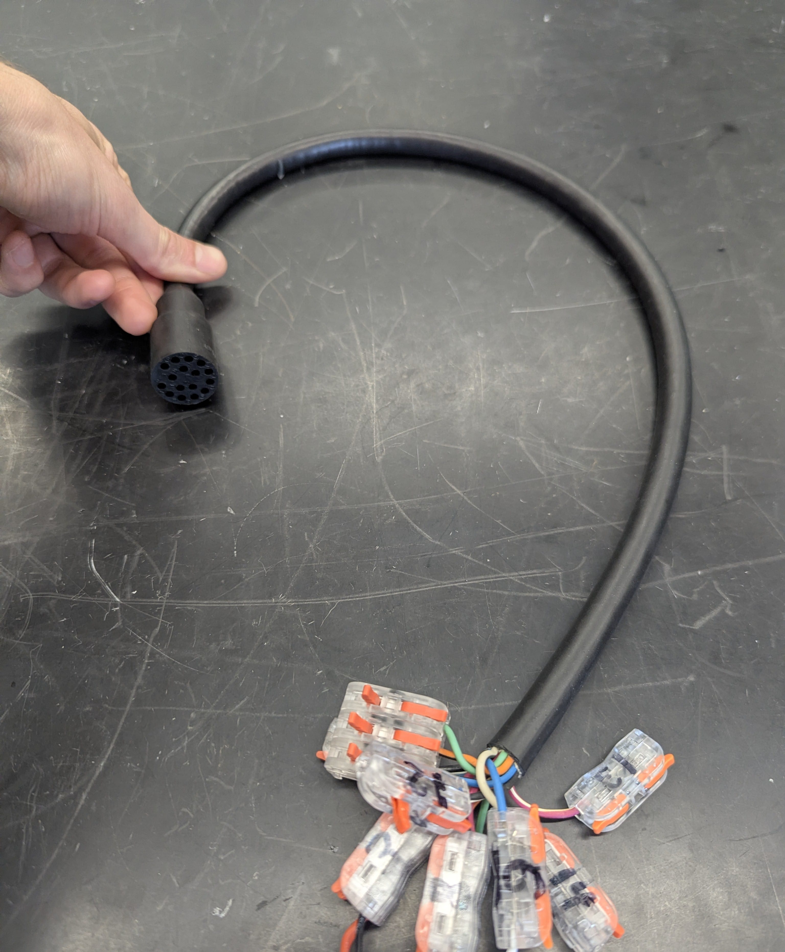
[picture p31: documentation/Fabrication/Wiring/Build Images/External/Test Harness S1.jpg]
Test Harness S1
Connect a quick connector to each of the wires of the 16 pin subcon pigtail following the left column color codes (or 'ISMS Housing Side') of the  [SubCon Octopus Cable Key.pdf](<./SubCon Octopus Cable Key.pdf>) wiring chart

> [!TIP]
>
> It can be helpful to number each quick connector with a sharpie to avoid having to refer to the color chart every time.

ISMS Recommended Topside Wiring

Next connect the quick connectors to the wires from the connectors made in the previous section following the overall wiring chart (or combining the powers and grounds to one power supply if that is what is available).

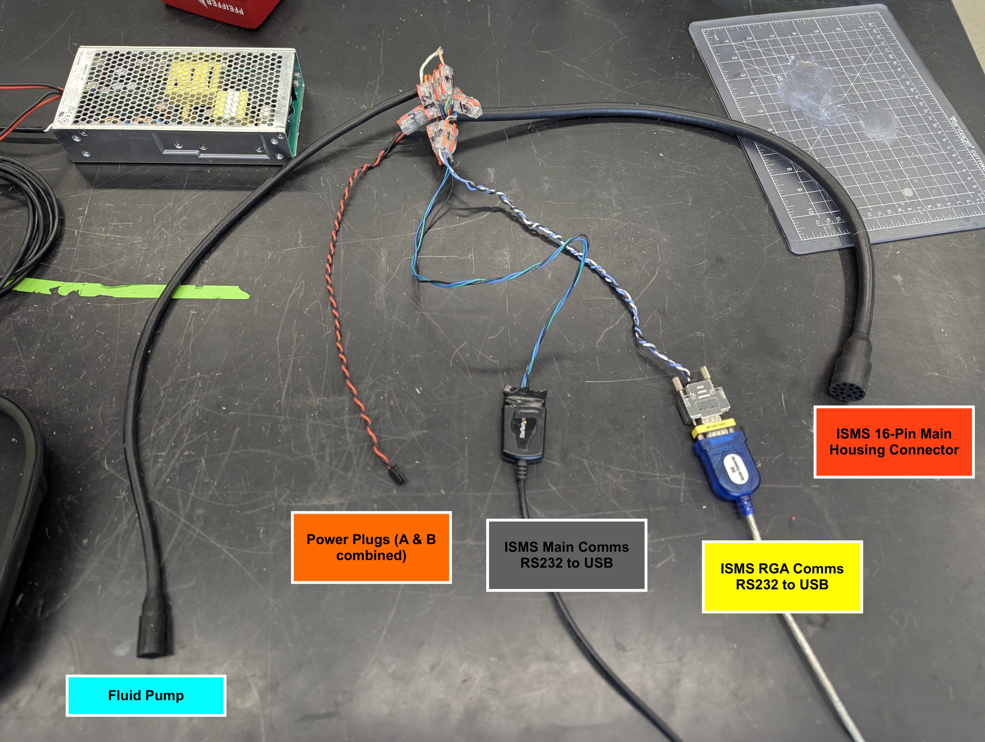
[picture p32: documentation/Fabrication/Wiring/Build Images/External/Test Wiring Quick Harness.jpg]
Test Wiring Quick Harness


> [!NOTE]
> This photo shows a slightly different wiring layout/schema than the recommended topside wiring diagram above; however, it works well if you only have one (250w or more) power supply to test with! It also has the subconn for the fluid pump attached.

This is a great oportunity to finally test all the systems of the ISMS and make sure everything is tight! If you are having trouble with the RGA or main Serial connection, check the internal connector wiring and/or install a null modem adapter if you didin't correctly cross the RX and TX wires at the topside connector. You can test the RGA by plugging a full off-the-shelf DB9 Serial cable between the RGA and your laptop usb-to-rs232 connector in a pinch.

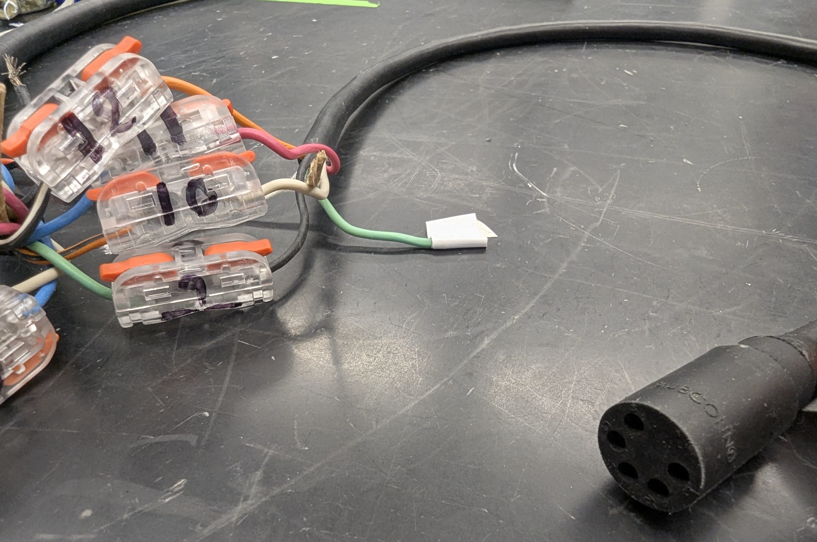
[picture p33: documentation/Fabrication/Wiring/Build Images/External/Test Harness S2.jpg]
Test Wiring Quick Harness


Next add the Fluid pump (and optional pH probe subconn) following the same [SubCon Octopus Cable Key.pdf](<./SubCon Octopus Cable Key.pdf>) color coding where the color code on the 16 pin connector on the left hand side of the chart are joined to to the wire color code of the fluid pump (and pH) subcons on the right hand side of the chart.

> [!NOTE]
>
> The fluid pump and pH probe subconns expose more pins than can map to the 16 pin ISMS Main Housing subcon. This was done intentionally so a future revision could change which features of the fluid pump are exposed by changing the octopus cable to dedicate more pins to the fluid pump or pH probe respectively. Any unterminated wires should be capped/taped to prevent shorts and left unconnected to anything.

### Permanent Splice

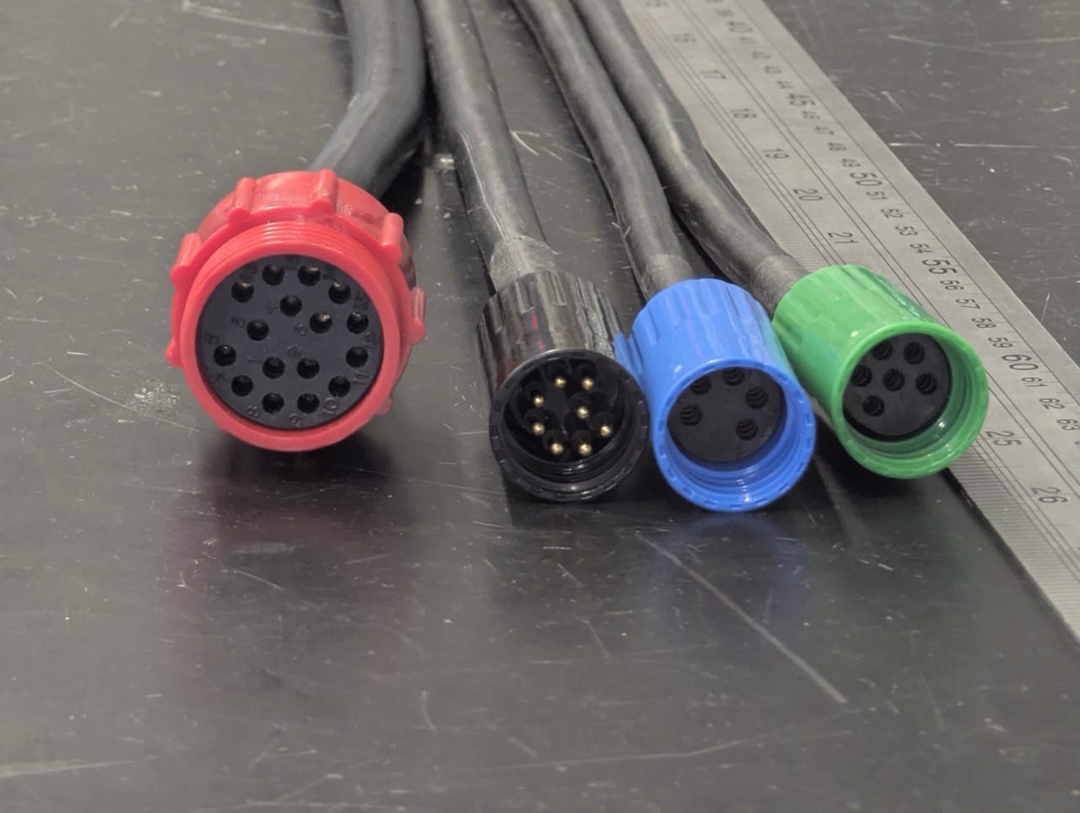
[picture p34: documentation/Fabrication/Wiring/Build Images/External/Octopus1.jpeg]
Octopus1


Match the locking sleeves onto the pigtails as shown.

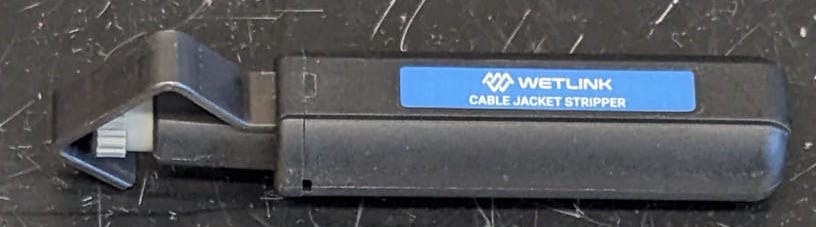
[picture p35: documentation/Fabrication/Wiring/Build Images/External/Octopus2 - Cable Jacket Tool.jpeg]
Octopus2 - Cable Jacket Tool


Use a tool like this or  using either technique shown in [this guide](https://bluerobotics.com/learn/cable-stripping/) to strip back the outer sheath

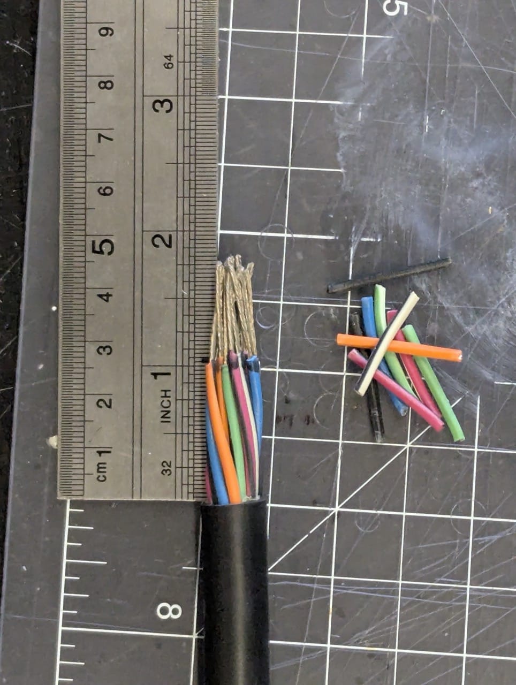
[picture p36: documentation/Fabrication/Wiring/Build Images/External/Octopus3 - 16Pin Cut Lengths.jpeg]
Octopus3 - 16Pin Cut Lengths


Cut the 16 pin outer sheath back 1 3/4" and strip each conductor 3/4"

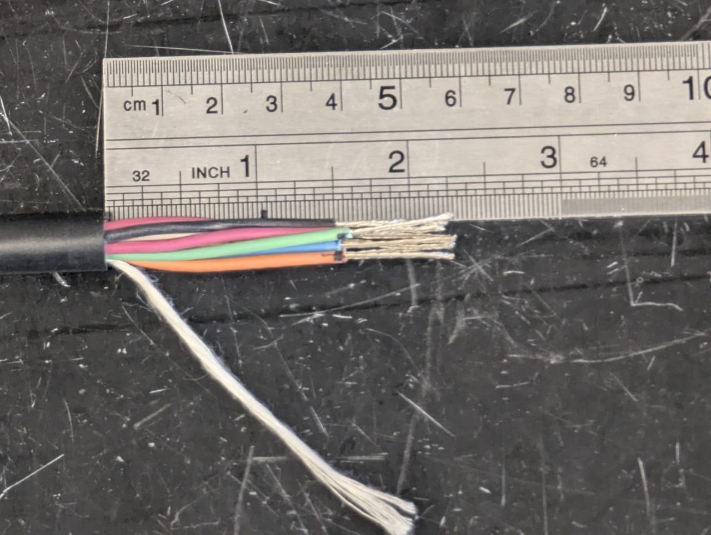
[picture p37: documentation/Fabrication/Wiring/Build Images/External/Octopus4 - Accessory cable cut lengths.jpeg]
Octopus4 - Accessory cable cut lengths


For every outer cable strip back 2 1/4" and strip 3/4"

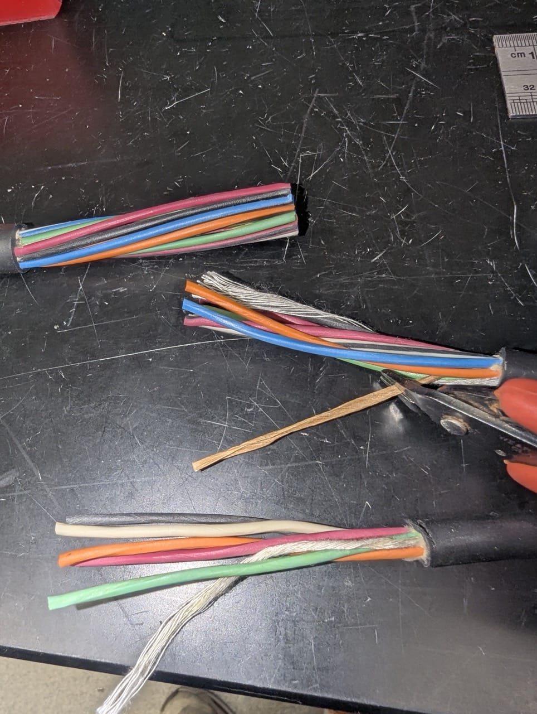
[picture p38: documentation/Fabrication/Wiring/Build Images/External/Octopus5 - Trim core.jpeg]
Octopus5 - Trim core


Cut just the inner core back (but not the tension cord if possible)

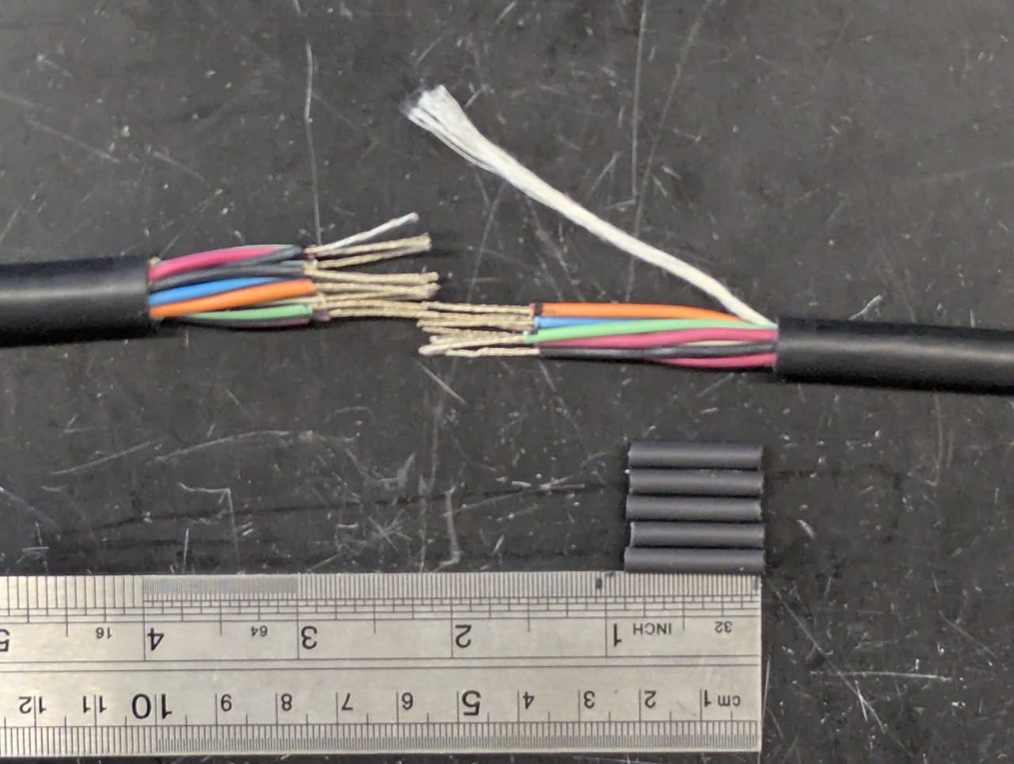
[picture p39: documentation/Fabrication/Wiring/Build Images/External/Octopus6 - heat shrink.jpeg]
Octopus6 - heat shrink


Cut 7/8" long heat shrink tube and slide onto the 8 pin connector side.

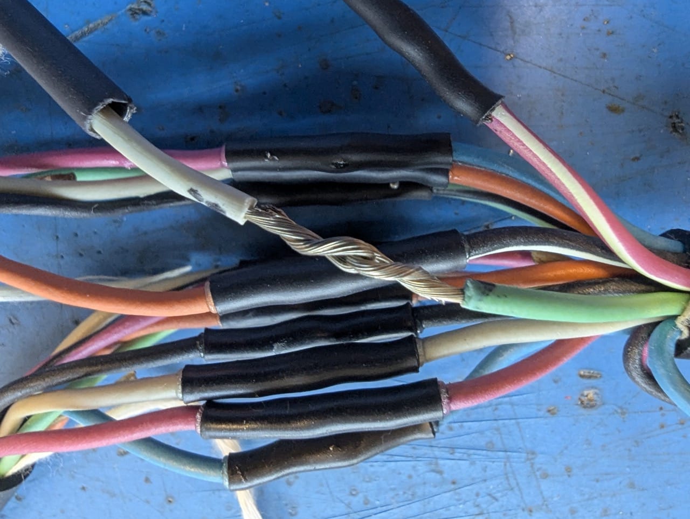
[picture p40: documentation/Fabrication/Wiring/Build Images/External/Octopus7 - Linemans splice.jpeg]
Octopus7 - Linemans splice


Do a lineman's splice between the 16 pin and 8 pin following the  [SubCon Octopus Cable Key.pdf](<./SubCon Octopus Cable Key.pdf>) wiring chart

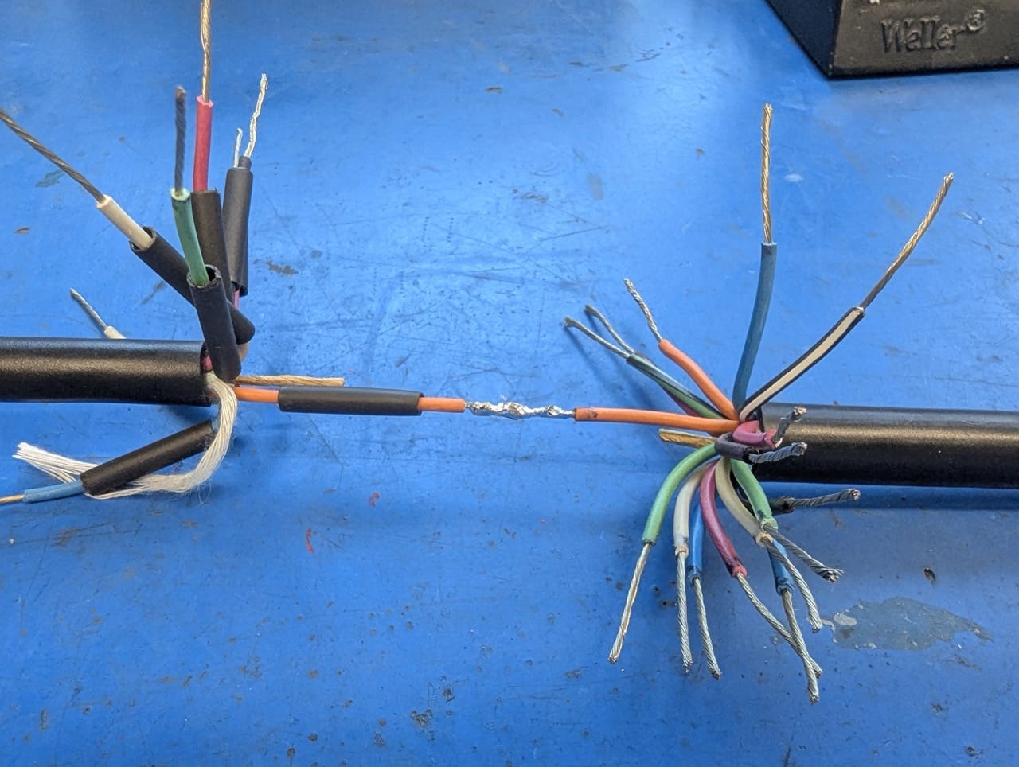
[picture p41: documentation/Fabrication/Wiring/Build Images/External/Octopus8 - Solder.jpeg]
Octopus8 - Solder


Solder each connector.

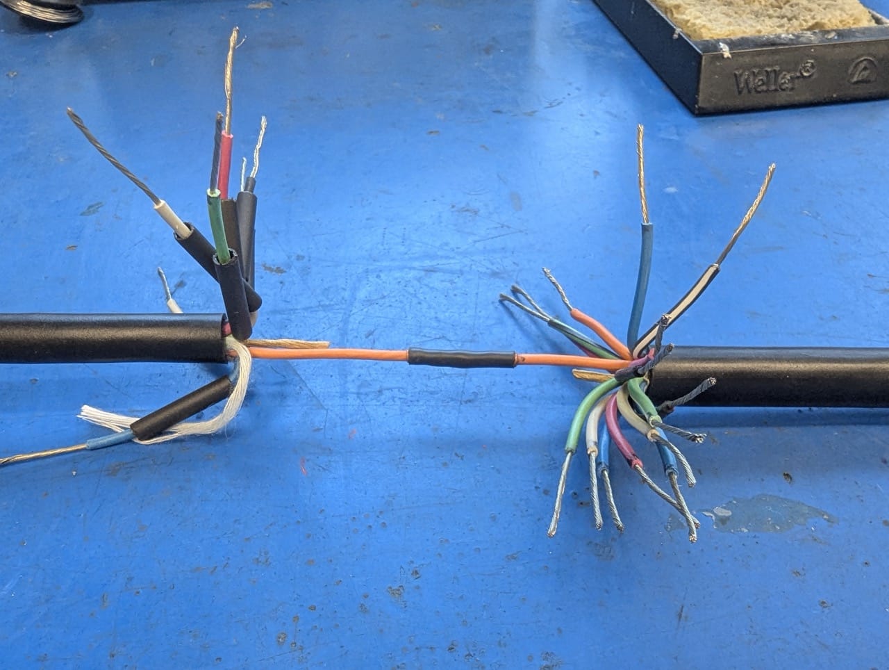
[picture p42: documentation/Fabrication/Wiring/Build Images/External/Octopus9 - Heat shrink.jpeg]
Octopus9 - Heat shrink


Slide heat shrink over the connector and shrink it, repeating for each conductor.

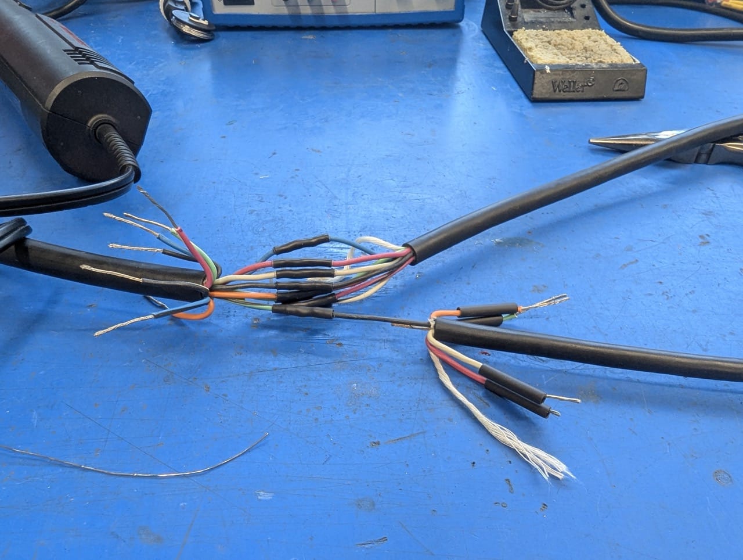
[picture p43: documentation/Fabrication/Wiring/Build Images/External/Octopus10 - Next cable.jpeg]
Octopus10 - Next cable
 Repeat for the other cords keeping them untangled as much as possible and inline with the 16 pin connector.

Cut a 1" section of firm rubber rod as a core material.

Wrap/twist the cords around the center core and tape the center to hold things together.

### Potting

Use the [molds](https://www.seascapesubsea.com/product/reusable-flexible-casting-molds/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) and [mold clamps](https://www.seascapesubsea.com/product/casting-mold-clamps/?attribute_size=Standard).

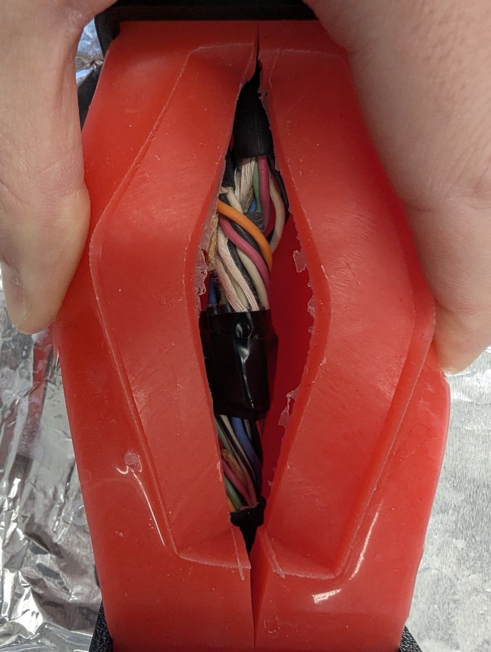
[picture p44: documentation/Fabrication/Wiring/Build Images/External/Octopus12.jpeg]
Octopus12


put the wire bundle in the mold so that it is floating on each side. try to keep the silicone mold seams as aligned to their orignal positions as feasable while putting the black or metal mold clamps on.

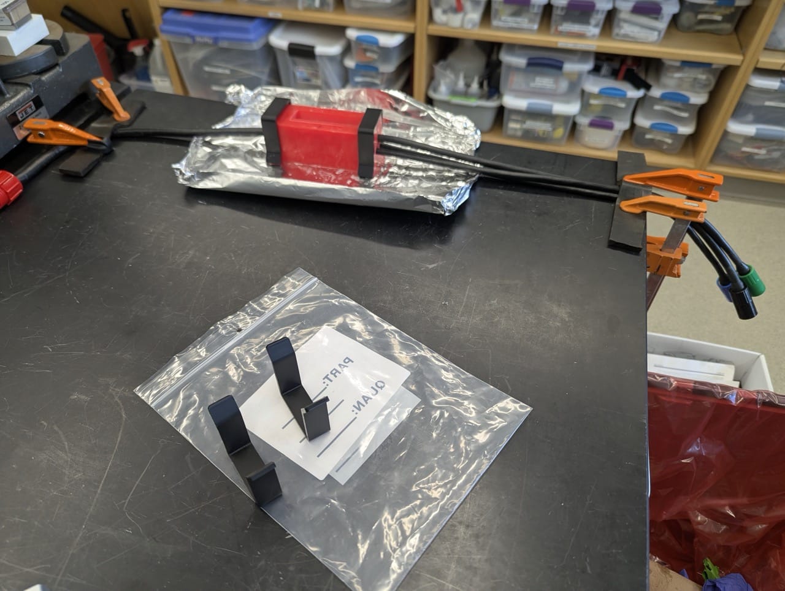
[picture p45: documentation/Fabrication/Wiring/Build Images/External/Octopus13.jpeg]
Octopus13


Stretch the cables with clamps so they are taught within the mold and have some twist int the cables so they sit more tightly bound in the mold.

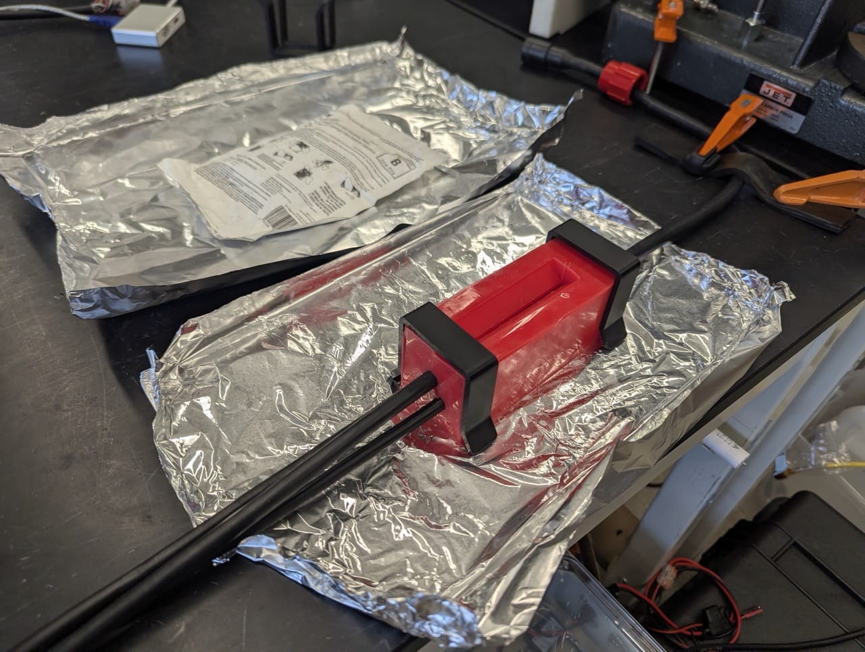
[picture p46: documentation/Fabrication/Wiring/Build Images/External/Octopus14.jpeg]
Octopus14


Add a drip catch area.

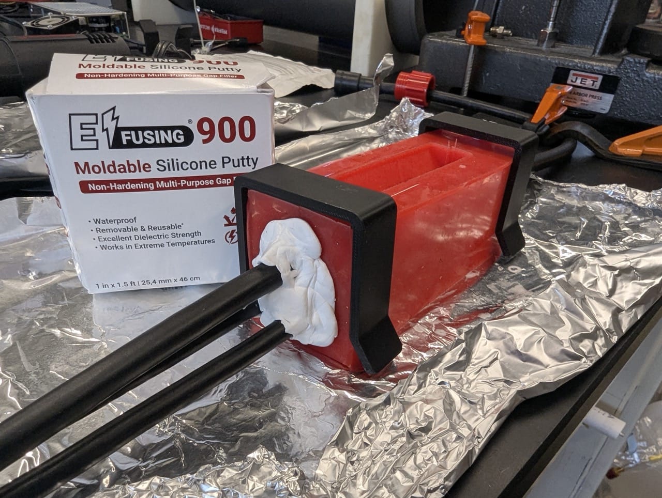
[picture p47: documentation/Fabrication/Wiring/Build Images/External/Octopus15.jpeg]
Octopus15


Put non-hardening silicone putty around the outside of the mold and cables to seal any cracks and openings in the sides of the mold!

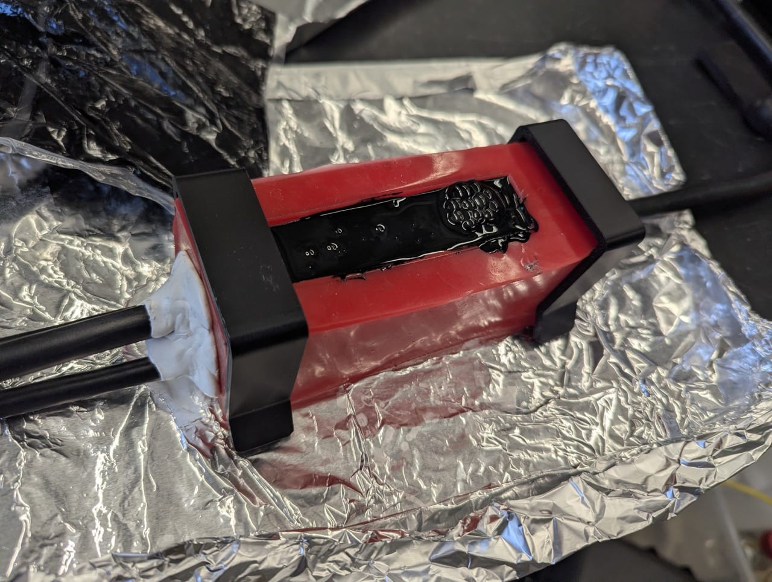
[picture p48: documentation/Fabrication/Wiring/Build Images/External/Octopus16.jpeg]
Octopus16


Mix and poor the Scotchcast compound follwing mfg directions, jiggle the mold to release air bubbles.

**Octopus cable potting checklist**:

- [ ] Correct locking collars slid on subconn ends.
- [ ] Wire heat shrink slid on each conductor and then soldered using the lineman's splice
- [ ] Free floating conductors are capped/taped.
- [ ] Correct wire continuity verified.
- [ ] Heat shrink shrunk.
- [ ] Wires taped around central rubber rod core to provide separation & rigidity.
- [ ] Cable outer surfaces prepped & sanded.
- [ ] (Optional) Mold-release applied to mold.
- [ ] All wires in mold and outer square mold clamps installed.
- [ ] Potential potting drip gaps sealed with silicone non-drying putty and area prepared for pouring.
- [ ] Wires tensioned and centered in mold cavity (not too near edges or top or bottom).

## Next Build Section: [Fluid Pump](<../Fluid Pump/README.md>)

## Appendix

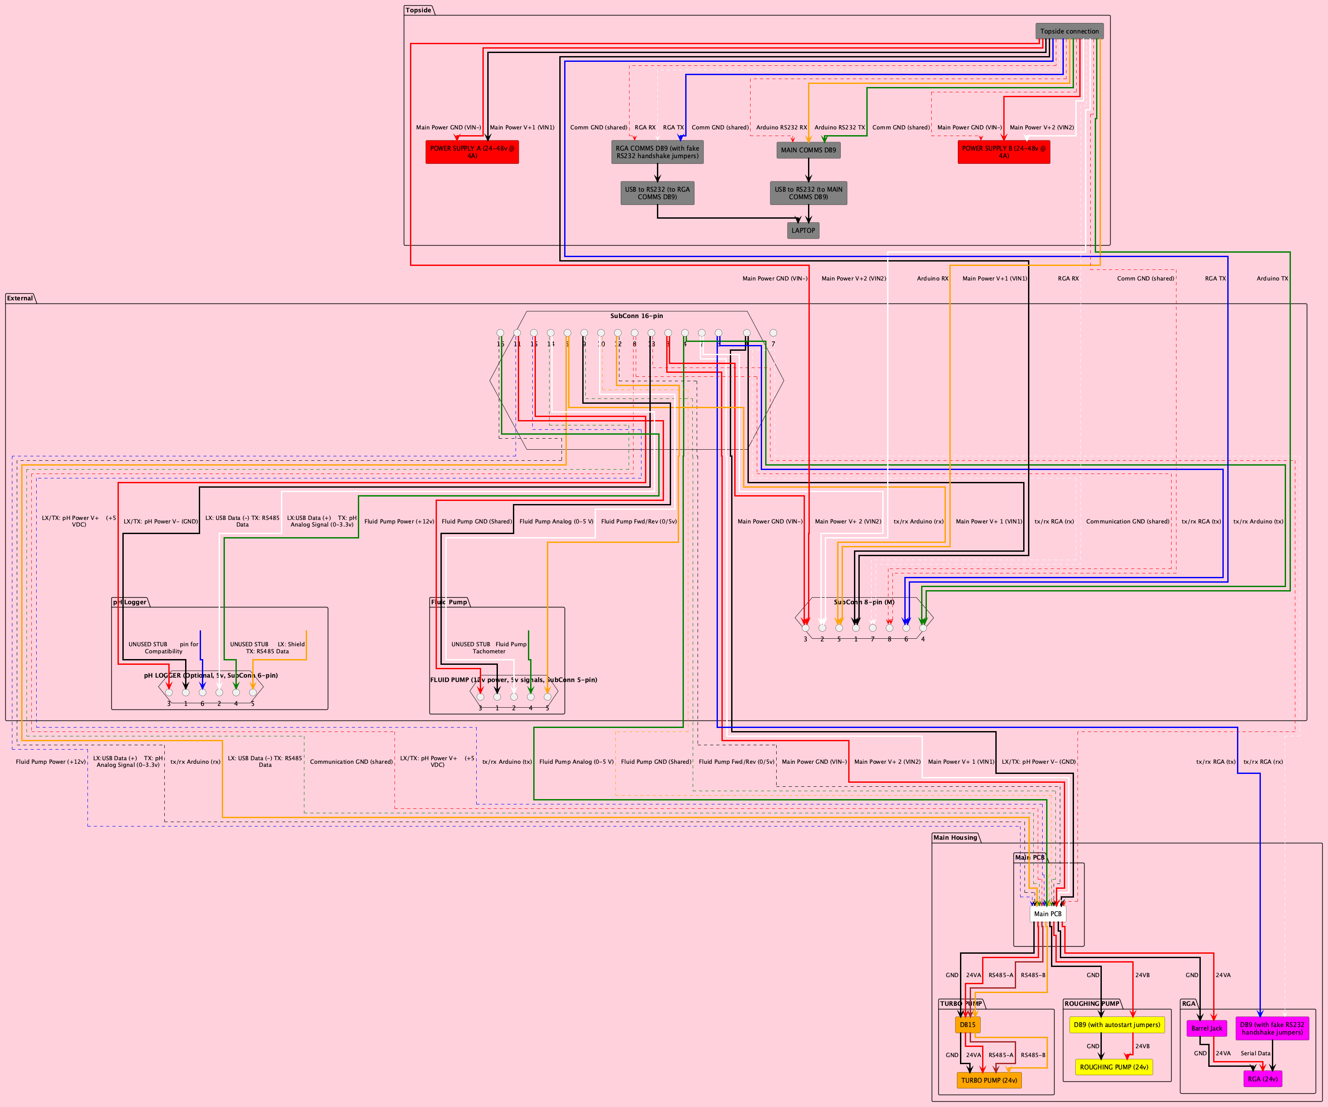
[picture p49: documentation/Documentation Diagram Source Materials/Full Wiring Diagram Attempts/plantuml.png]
plantuml
A full ISMS system wiring diagram can be found here:  ../../Documentation Diagram Source Materials/Full Wiring Diagram Attempts/plantuml.png

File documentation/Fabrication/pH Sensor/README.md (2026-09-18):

# pH Probe Notes

Current design involves a fully standalone AquapHOx-LX pH meter that is correctly timestamped to the same time zone as the operator computer, so data logs can be correlated after recovery.

### Installing the AquapHOx-LX pH logger:

The AquapHOx-LX pH logger sits after the ph probe on the fuid path.

3D print options:

- **Option 1 [Recommended]:** Print using multi-jet fusion from a commercial service such as Shapeways, Jawstec or Craft cloud with nylon  pf12 or other plain nylon material - MJF allows a watertight part that is compatible with NPT tapping and threading without cracking.
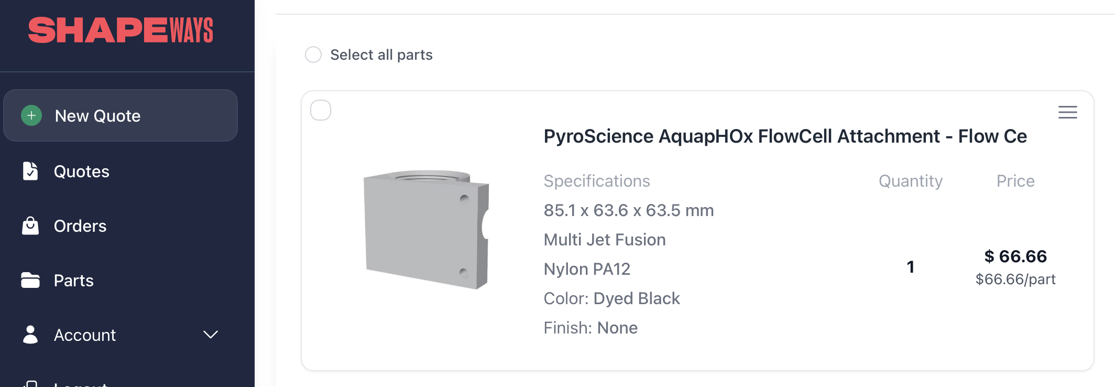
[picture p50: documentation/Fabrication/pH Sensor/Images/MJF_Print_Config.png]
MJF_Print_Config
  - 

- **Option 2:** Use a standard FDM printer and with a hollow print profile and no bottom layers and fill with epoxy resin from the bottom - 
  - Follow the guidelines in this article: https://blog.prusa3d.com/watertight-3d-printing-pt1-vases-cups-and-other-open-models_48949/
  - SlicerSettings1
  - Once printed, cut away any internal bridging filaments, flip upside down and fill with a slow cure epoxy or resin such as [MG Chemicals 832HD](https://www.digikey.com/en/products/detail/mg-chemicals/832HD-50ML/9658009)

- **Option 3:** 3D print the flow cell attachment for the AquapHOx-LX using a 100% fill FDM print with a UV-resistant filament (Least watertight option)

#### Threading

Once printed and/or hardened, drill a 'r' size pilot hole for 1/8" tap and then use a 1/8" NPT pipe tap to make threads in the input and output fluid ports - the tap should go in until there are 6-7 tap cutting threads remaining visible above the port face.

Install 1/8" NPT to Swagelok 1/4" brass or plastic tube fitting adapters into the NPT holes we just tapped with NPT threads wrapped in 3+ wraps of PTFE tape.

### Using the AquapHOx-LX pH meter:

See the Pyroscience software documentation - use the usb-to-subconn adapter cable included w the AquapHOx-LX to initialize it and begin logging - the  AquapHOx-LX is not yet integrated into the software of the ISMS and functions as a fully standalone logger.

### Alternative designs:

The onboard PCB was orignally designed to be electrically pin compatible with the [Pyroscience Pico pH Sub](https://www.pyroscience.com/en/products/all-meters/pico-ph-sub) pH Probe, however this probe requires waterproofing the back end of the bulkhead part. As such, it would need an additional oil-compensated enclosure design and subconn or integration into the main housing end cap, which was deemed to tricky while maintaining structural integrity of the main end cap at the time. Software has not been written for any pH probe but should be fairly trivial to integrate if desired following the same patterns as the other serial sensors in the codebase.

## Next Build Section: [Vehicle Integration Guide](../ISMS%20V3%20Vehicle%20Integration%20Guide.md)

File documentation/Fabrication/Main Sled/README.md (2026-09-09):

# Main Sled Build

The ISMS is built onto a sled that slides into the main housing and is attached to the housing endcap with the inlet and other ports.

### Assembling Inlet

Parts required:

- Inlet Base (Ti)
- Inlet cap (Ti)
- Frit
- Membrane Material (backed teflon or mesh reinforced PDMS)

Tools Requried:

* 16mm or 5/8" hollow cuttout tool and hard teflon "cutting board"
* Hammer or cutting press.

Cut out a disk from the membrane using the cutout tool (or laser cutter for PDMS composite membranes - ask kyle for laser cutter settings used)

p00001

Screw the 1/4" NPT to Swagelok 1/4 tube fittings into the inlet top cap fluid ports with ~2 wraps of standard PTFE pipe wrap tape on each fitting.

p00002

Lightly grease o-rings and Add to their respective grooves (o-ring sizes smallest to largest:  TODO fill in )

Add frit in center of inlet base, taking note of any bevel on the edge of the frit, which should go DOWN if present so the surface of the frit and machined base surface (shown in blue) are as flush as possible.

p00002A

Another view of this step^

p00003

SideView-Inlet

Sandwich the Membrane on top of the frit - centered so it does not touch the greased o-rings - it should extend past the edges of the frit slightly. Holding the inlet cap above the base - align the screws and begin tightening - the grease of the smallest inner o-ring should allow it to cling to the groove in the underside of the cap. When you have the screws aligned and partially screwed in - slide down the cap onto the base checking that all o-rings stay centered in the groves and not pinched - in this way the smallest o-ring should be centered on the membrane without shifting.

p00004

Screw the BSPP to 1/8" tubing (yorlock brand) fiting into the vacuum side port and tighten so the rubber gasket makes a good seal.

> [!IMPORTANT]
>
> Since this side will be part of the vacuum chamber, wear gloves and avoid getting any residues on the interior of the inlet or fittings, also do NOT use Teflon tape as this is not a tappered NPT fitting.

p00005

Cut a roughly 101mm length of the PEEK plastic 1/8" OD tubing - this will serve as electrical isolation between the internal sled/vacuum chamber ground and the metal of the inlet/main housing/ocean. This isolation is nescesary for some host sub vehicles to detect electrical problems.

p00006

Connect the PEEK tubing to the inlet adapter fitting using brass swagelok ferrules (brass or stainless steel nut is ok and Yorlock is cross compatible with swagelok components/ferrules)

> [!IMPORTANT]
>
> While 1/8" swagelok/yorlock fittings should be tightened 3/4" turn past "finger tight" (See [Swagelok Fitting Installation](https://stavanger.swagelok.com/en/resources/tube-fitting-installation)), PEEK tubing is especially fragile, so err on the side of less tight and tighten as needed once you are able to test the capped vacuum performance. Replace if overtightened or visibly strained and try again with new brass ferrules - the brass is slightly softer than stainless ferules so that should help with over-tightening.

### Assembling Primary Housing Endcap

p00001

Screw in prevco dual seal vent plug ensuring both o-rings are present and lightly greased.

p00002

Screw in zincoid sacrificial anode (Do not use tef-gel or other insulating material between anode and endcap threads as this defeats the purpose)

p00003

Screw in Subcon 16pin male bulkhead with red FEMALE locking sleeve.
Make sure the o-ring provided with the Subcon bulkhead is lightly greased and dust/hair free before inserting.

Fill the 16 pin dummy plug holes with some Molykote 44 Medium grease and push onto the bulkhead to protect the bulkhead pins.

p00004

Apply teff-Gel to the surfaces marked in teal  (but not inside the o-ring grooves) to prevent galvanic corrosion/electron exchange between the inlet base and the main enclosure end cap while in seawater.

p00005

Add lightly greased o-rings to inlet avoiding getting tef-gel on the o-rings.

p00006

Apply a generous amount of teff-Gel to the threads of the 1/4-20 x 1" bolts with washers and affix to main end cap, making sure tubing ports are facing in a direction suitable to route the external fluid path.

### Assembling Sled Chassis

Machined Parts required:

- 4x rails (Machined brass)
- 1x electronics base plate (Machined brass)
- 2x center chassis spacer disks  (machined black Delrin plastic)
- 2x end chassis spacer disks  (machined black Delrin plastic)

p00001

p00002

p00003

The four bottom holes in the roughing pump will need to be tapped with an 10-32 thread tap to accept the screws. Apply a small amount of Swagelok VacGoop to the BSPP threads of the BSPP to YORLOK fitting and screw into inlet port of the roughing pump following BSPP fastening norms (screw till mostly tight then finish by screwing down nut over o-ring flange)

p00004

p00005

p00006

p00007

p00008

p00009

Screw in terminal blocks to laser cut mounting plate with M2.5 x 16mm screws and lock nuts, then ziptie plate to rails centered over the large flange of the turbo pump. The terminal slot marked "1" on the laser cut mount plate should be on the left side in this photo.

p00010

Attach main end cap with 5 screws to the end ring (Note how these screws screw INTO the endcap from the backside of the end ring).

p00011

Completed sled.

### Connecting Inlet to Vacuum

As of writing this part was the least settled. Two options exist:

- A) Add a lenth of small diameter capilary tubing between the inlet and vacuum chamber to reduce the total gas load on the RGA and hopefully achive tighter mass spectra peeks
- B) Go straight from inlet to vacuum chamber side port

In either case, the length of PEEK tubing that provides electrical insulation must still be there along with a union Swagelok tube fitting to connect the PEEK tubing to the capilary or a length of stainless tubin that can take a tighter bend than the pure PEEK tubing to go into the vacuum chamber side port.

Option A Shown here:

Option A

> [!TIP]
>
> Cap the vacuum chamber for now at the side port using a swagelok fitting plug. Once you have established that the capped vacuum is tight, then go back and finnish installing this connection

## Next build section: [Wiring](<../Wiring/README.md>)

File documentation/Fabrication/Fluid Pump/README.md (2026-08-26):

# Oil Compensated Fluid Pump - Build Guide

Finished Fluid Pump

CAD Here: [Link](<https://cad.onshape.com/documents/9e45e871d74b8539d6687f02/w/a3384ad6c22d56b5ea88b888/e/1e5f54e24d5f977d3ebdd65c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>)

### Parts

 listed in Fluid Pump section within the overall parts list for the ISMS

3D print the following part:

- [Fluid Pump Mount - Pump Mount for BR 3- Housing.stl](<./3D Print Models/Fluid Pump Mount - Pump Mount for BR 3- Housing.stl)

Laser Cut the following parts from the 23/64" thick accrylic sheet:

-  (Optional Jig x1)  [BR end cap drilling guide jig top plate.dxf](<./Laser Cut Designs/BR end cap drilling guide jig top plate.dxf)

- (Optional Jig x1)  [BR end cap drilling guide jig bottom plate.dxf](<./Laser Cut Designs/BR end cap drilling guide jig bottom plate.dxf)

- (Optional Jig x2)  [BR end cap drilling guide jig spacer plate.dxf](<./Laser Cut Designs/BR end cap drilling guide jig spacer plate.dxf)

-  [WTE3-P-END-CAP-R1 - End Cap Plate W Diaphragm Opening.dxf](<../Laser Cut Designs/Fluid Pump/WTE3-P-END-CAP-R1 - End Cap Plate W Diaphragm Opening.dxf)

- [Fluid Pump End Cap O-Ring Groove.eps](<Laser Cut Designs/Fluid Pump End Cap O-Ring Groove.eps>)

  - Special Note: This end cap requres laser engraving or machining out the o-ring groves to a depth of approximately 1.9 mm or 3D printing the matching 3d model: [Customized_WTE3-M-END-CAP-4-HOLE-R1 - Fluid Pump End Cap plate W penetrator holes.stl](<Laser Cut Designs/Customized_WTE3-M-END-CAP-4-HOLE-R1 - Fluid Pump End Cap plate W penetrator holes.stl>)  with a watertight but durable method like SLA printing with a non-brittle resin.

    On a 75 watt Universal Systems CO2 Laser Cutter these parameters worked best - you will likely need to experiment with your laser cutter to get appropriate results before making a full cutout:

    	raster engrave settings for 1.9mm deep cut: 19% Power, 15% Speed, 1000 PPI, 0.359" z-axis height.

    See the original CAD for the desired result (end cap shown in black): https://cad.onshape.com/documents/9e45e871d74b8539d6687f02/w/a3384ad6c22d56b5ea88b888/e/1e5f54e24d5f977d3ebdd65c

### Cut the diaphragm

Cut the diaphram from the Buna-N rubber 1/8" thick sheet either with a water jet or using the jigs:

- Cut out of the rubber sheet a rough circle larger than the final shape with an exacto knife.
- Clamp the rubber circle in a stack consisting of the jig stack cut out of 1/4" thick accrylic: Drilling guide template bottom plate > Bunna Rubber sheet > Drilling guide template spacer plate (x2) > Drilling guide template top plate
- Screw together jig with 8-32 x 2" screws and nuts and clamp in a vice
- Drill holes with a 1/8" extended shank drill bit or 1/8" milling drill bit
- Cut exact outer perimeter with an Exacto knife

### Make diaphragm end cap

1. Bevel the inner edge of the Accryclic end cap plate with diaphragm opening using an exacto knife so the diaphragm will not rub against a sharp edge when expanding.
2. Sandwich the diaphragm against the Blue Robotics black aluminum end cap flange along with the face seal o-ring included w the blue robotics flange using 6 m3 x 16mm screws.
   Fluid Pump Pressure Compensation Diaphgram

### Swap micropump factory case for 3D-Printed mount

Remove the micropump-provided housing by unscrewing the two screws on the pump head and firmly twist the pump head to release it from the plastic housing. Pinch and remove the grommet so the wires can come throught the port in the housing. Slide the Micropump electronics into the 3D printed mount, aligning the screw holes as shown. Re-attach the pump head and reinstall the screws holding the pump head to the electronic drive.

Micropump Mounting Sandwich

Mcropump Mounting Sandwich Screws

### Install penetrators in oposite end cap.

Assemble the WTE based on the BR guide: https://bluerobotics.com/learn/wte-vent-assembly-guide/

All penetrators should be oriented witht the nut on the inside surface and the o-ring on the outside surface of the accrylic sheet with a thin layer of molykote 111 or 44 medium grease on the o-rings

The fluid path bulkheads should be installed just like  the other bulkheads, except the o-ring fits into the groove in the acrylic not the bulkhead.

Tighten all penetratrators firmly like described in the blue robotics WTE guide

Use m3 Screws to fasten the end cap onto the flange with the face o-ring (lightly greased)

Penetrator End Cap

4. Splice electrical connections

Following the wire color chart for the external side fluid pump in the [SubCon Octopus Cable Key.pdf](<../Wiring/SubCon Octopus Cable Key.pdf), splice each wire from the fluid pump to the Subconn Bulkhead with individual heat shink to prevent shorts. You can unplug the wires from the pump drive electronics for soldering. Tie back the unused wires and string using heat shrink and seal with glue to avoid shorts.

Pass cable through tubing and reconnect to pump drive connector on other end. Connect pump to diapragm end cap flange screw holes with 2 M3 x 16mm screws in the pocket holes.

Wiring Splice

 Micropump Wire Join

Wire Connection

Pump Pocket Screws

### Connect fluid path tubing to Micropump

Wrap the two 90* Elbow fittings with 1/4" standard thickness (non-ss) teflon tape for 1 & 3/4 wraps each. Screw into pump inlet & outlet until each are facing straight relative to the central axis of the Blue Robotics housing. If tightening becomes difficult or is too loose at this angle, try a different number of teflon tape wraps.

Attach two 7" long sections of 1/8" OD Nylon tubing (in red color here) to the ports using swagelok nylon ferrules instead of the stainless steel ones from the fittings.

Micropump NPT Elbow Fitting Orientation

Connect to swagelok bulkheads on end cap, again swapping plastic ferrules (and/or nuts) for the stainless steel ones from the swagelok bulkheads.

Install Locking cords

### Test

Connect subconn to main ISMS bottle and test Fluid pump with water.

### Mineral Oil Fill

Fill the pump housing with oil using a vacuum fill if possible.
Vacumm connection instructions using a hand vacuum pump: https://bluerobotics.com/learn/using-the-vacuum-test-plug/#testing-the-test-setup

To do a vacuum fill you'll need a tubing, a secondary vacuum-safe sealed jar or container with two tubes to act as a oil reservoir and trap and a vacuum pump .

1. Fill the housing about 3/4 with mineral oil & then close and seal the housing.
2. Fill the trap container with enough oil to fill the remaining volume inside the housing without covering the outlet tube.

2. Connect a tube from the pressure relief valve with the red backfill adapter screwed on and the Vacuum plug in place to the oil reservoir / trap so the tube sits at the bottom in the oil in the trap.
3. Connect the other tube from the headspace of the trap to the vacuum pump.
4. Pump a vacuum in trap - which should pull a sufficient vacuum in the enclosure as well
5. wait for degassing to occur.
6. Re-pressurize the vacuum line slightly to force the oil into the enclosure with slight positive pressure so the diaphragm bows outwards .
7. Unscrew the backfill adapter to seal the oil in - some may dribble out.

Vaccum Fill Setup

## Next Build Section [pH Probe](<../pH Sensor/README.md>)

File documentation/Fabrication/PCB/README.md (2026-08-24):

# ISMS V3 Internal PCB build guide

The ISMS v3 internal PCB was designed and assembled by Acbotics Research.

They are the best source of answers about this build.

### Useful files:

##### Bill of materials

electronic parts needed to assemble the board (BOM: Bill of materials):

[100818_v1.0.1_BOM_Std.csv](<mass spec board v1.0.1/assembly/100818_v1.0.1_BOM_Std.csv>)

##### Electrical Schematic

Schematic with notes in green - taken while going through board schematic with Actbotics staff.

 [100818_v1.0.1_Schematic_WITH_NOTES.pdf](<mass spec board v1.0.1/100818_v1.0.1_Schematic_WITH_NOTES.pdf>)

**Assembly Drawing**

Shows where the final components will be layed out.

 [100818_v1.0.1_Assembly.pdf](<mass spec board v1.0.1/100818_v1.0.1_Assembly.pdf>)

##### Gerber Files

Used by PCB Factories to create the various layers in the PCB stackup. The zip file  [100818_v1.0.1_FAB.zip](<mass spec board v1.0.1/100818_v1.0.1_FAB.zip) is what you would give to a PCB house to have this board created.

##### Pick 'n Place files

Given to an automatic assembly service that will place and solder all the components onto the board by machine (Eg. PCBway PCBA)  [100818_v1.0.1_PnP_Std_TOP.csv ](<mass spec board v1.0.1/assembly/100818_v1.0.1_PnP_Std_TOP.csv) (top side) & [100818_v1.0.1_PnP_Std_BOT.csv](<mass spec board v1.0.1/assembly/100818_v1.0.1_PnP_Std_BOT.csv) (Bottom Side>)

#### Changes from as designed

See [100818 Rework.docx](<PCB commisioning and functionality testing Documentation from Acbotics Research/100818 Rework.docx>)

Also connectors could be redesigned to accommodate the Fwd/Rev fluid pump 5v output signal in a shared connector with the other fluid pump pins.

### Commissioning a new board

see [100818 DVT.docx](<./PCB commisioning and functionality testing Documentation from Acbotics Research/100818 DVT.docx>)

## Next Build Section: [Vacuum System](<../Vacuum System/README.md>)

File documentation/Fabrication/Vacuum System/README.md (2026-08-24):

# Vacuum System Assembly

**Parts required:**

- See vacuum parts list section in main parts spreadsheet.

### Unpacking Components

s0

If already installed, remove the RGA electronics enclosure from the Quadropole tube by unscrewing the long body screws and sliding/pulling the case back firmly.

s1

If the turbopump has a small DIN flange attached to the outlet port, unscrew it using a wrench on the flat sides.

### Assembling the Vacuum Stackup

While assembling the vacuum components, make sure your work area is relatively dust/residue free, wear fresh gloves, and avoid touching inner surfaces that will be exposed to vacuum where possible.

> [!tip]
>
> Have a sturdy chemistry lab stand with a flask clamp, affixed to the table you're working on to provide a second grip to keep the vacuum stack upright as it grows.

> [!IMPORTANT]
> ALWAYS USE FRESH COPPER GASKETS whenever you must open, re-tighten or re-assemble any vacuum flanges!!

s2

With the turbo pump upright, lay a fresh copper gasket on the circular "kife edge" followed by the 2.75" to 4.5" Conflat flange adapter and align the holes.

s3

Screw together with the silver plated 5/16-24 x 2.00" bolts untill just snug, but don't tighten yet! Use Nordlock/wedgelock washers on the back side between nuts and bolt holes. Do not use washers on the bolt head side since the bolt head flare already distributes the load.

> [!NOTE]
>
> The silver plating on the bolts serves two important functions: It lubricates the bolts and provides a dissimilar metal to prevent galling without the need for lubricants which may off-gas and contaminate the mass spec signal.

s4

Stack the rest of the vacuum chamber components into a small tower, each with a fresh 2.75" CFF copper gasket. Pay attention to the alignment of several key features: The turbo pump control box and side port on the second small flange facing the front side, while the two long alignment pins on the RGA quad tube are towards the back in this illustration. Lower the quad tube gently to avoid hitting the cage on the inside of the vacuum flanges.

s5

Screw together till finger-snug using the silver plated 1/4-28 X 2-1/2" bolts that were order along with a Stainless steel normal washer.

### Tightening Bolts

s6B

Once you are satisfied that everything is properly rotated and aligned, use the fixed lab stand mentioned earlier to hold the Quadropole tube and keep everything steady

s6

while tightening all the bolts we've installed so far (so both the bolts in the 4.5" CF flange and 2.75" CF flanges).

When tightening conflat flanges, tighten every other bolt in an alternating pattern. Use a long wrench or wench extension to get maximum leverage. When done right you should be able to keep tightening each set of bolts past where they used to feel stuck many times - this is the copper gaskets deforming under the stress - which is what we want to get a perfect seal. A fully tightened conflat flange pair should have a gap only slightly larger than a sheet of paper- You'll know you are done when you physically can't tighten ANY of the bolts with a long wrench.

> [!TIP]
>
> To gain leverage on the turbo pump without scratching it, lay a second small wrench between the star bolt heads on the 4.5" base so the wrench handle/bar gets stuck between the boltheads and the conflat flange outer surfaces and allows you to put torque on it.

### Adding Tube Fittings

s7

Spread a small amount of swagelok VAC Goop on the BSPP threads of the BSPP to 1/4" Yorlock tubing fitting to prevent galling.

Twist BSPP threads into the port until close to the right angle, then finger tighten the loose nut down onto the fitting to seal temporally.

> [!IMPORTANT]
>
> BSPP, yorlock tube, and swagelok tube are not tappered thread fittings, so DON'T USE PTFE TAPE / "TEFLON" TAPE on these threads - it won't help with sealing and could hurt it.

s8

Note for future steps: The bspp fitting is angled slightly down to accommodate the tubing run. Get it roughly aligned now, with the idea that you'll need to loosen the lower nut and get the angle exact when you install the tubing run shown in orange later.

s9

Screw the in the 1/8" NPT to 1/8" swagelock tube fitting into the side port. Wrap with 2-4 wraps of teflon tape. You may need to play with the number of wraps to get the angle right.

> [!IMPORTANT]
>
> When working with NPT fittings, always use 2 or more wraps of standard thickness Teflon/PTFE tape (or slightly less with 'stainless steel' rated PTFE tape). The biggest risk is getting bits of teflon tape inside the vacuum chamber which can fly into the turbo pump and jam or dent the blades. SO, make sure the teflon tape wrap doesn't extend past the last screw thread, and that you clean the inner and outer threads after removing teflon-taped fitting with a pick before re-inserting a new fitting with new teflon tape. Orient the chamber down so any tape bits don't fall into the vacuum chamber while cleaning it.

### Final RGA Assembly

s10

s11

Lastly slide the RGA Electronics box over the pins and tighten using the long screws that run from the back of the RGA electronics box.

### Bending Vacuum Tubing Run

Parts & tools required:

- 1/4" OD x  Stainless steel continuous straight tubing - about 4ft long.
- 1/4" tubing bend tool
- Protractor, Pen & Paper
- Clamps and a flat work surface.

These are the steps to create the tubing run that goes between the Roughing inlet and Turbo Pump outlet shown here: https://cad.onshape.com/documents/b6c7e603ca3691b93cbc85d9/w/9ed404cfa2f2ee86ebc2e394/e/7f697bb443b9acb569f2a20e

1. Starting from one end of the tube, mark off the following distances (all relative to your 'start' end of the tube)

   | **Distance from start** | **Bend amount AFTER each mark**                              |
   | ----------------------- | ------------------------------------------------------------ |
   | 82mm                    | 15° - PLANE A                                                |
   | 139mm                   | -15° - PLANE A                                               |
   | 186mm                   | 8.43° - PLANE B (PLANE B is perpendicular to PLANE A, Rotated 90° along the axis of the tube) |
   | 332mm                   | 45° - PLANE B                                                |
   | 395mm                   | -90° - PLANE B                                               |
   | 460mm                   | 90° - PLANE B                                                |
   | 526mm                   | -90° - PLANE B                                               |
   | 600mm                   | 45° - PLANE B                                                |
   | 659mm                   | 90° - PLANE C - (perpendicular to both plane A & B; axially rotated 59° CCW relative to PLANE B (or 31° CCW relative to PLANE A)) |
   | 764mm                   | -90° - PLANE C                                               |
   | 807mm                   | END CUT                                                      |

Step1

Bends 1 & 2:

Step2&3

Bend 3 (Clamping):

Step4A (./Images/Tubing Bending Steps/Step4A (Clamp).jpeg)

Bend 3 (Jig):

Step4B (./Images/Tubing Bending Steps/Step4B (Jig).jpeg)

Bend 3 (Actual Bend):

Step4C (./Images/Tubing Bending Steps/Step4C (Bend).jpeg)

Bend 4:

Step5

Bend 4 (Finished):

Step5 (./Images/Tubing Bending Steps/Step5 (Finished).jpeg)

Bend 5 (Finished):

Step6 (./Images/Tubing Bending Steps/Step6 (finished).jpeg)

Bend 6:

Step7

Bend 7 (finished):

Step8(./Images/Tubing Bending Steps/Step8(finished).jpeg)

Bend 8 (finished):

Step9(./Images/Tubing Bending Steps/Step9(finished).jpeg)

Bend 9 (Compound Angle setup):

Step10A(./Images/Tubing Bending Steps/Step10A(Compound Angle).jpeg)

Bend 9 (Compound Angle, actual 90* bend):

Step10B(./Images/Tubing Bending Steps/Step10B(CompoundAngle).jpeg)

Bend 10:

Step10(./Images/Tubing Bending Steps/Step10(finished).jpeg)

Bend 10 (another view):

Step11

End Cut:

Step12(./Images/Tubing Bending Steps/Step12(end cut).jpeg)

All done! We'll install it between the two vacuum pumps after the sled is assembled.

## Next build section: [Main Sled Build](<../Main Sled/README.md>)

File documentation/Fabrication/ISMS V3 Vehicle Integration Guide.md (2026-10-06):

# ISMS V3 Vehicle Integration Guide

The ISMS can be integrated into various vehicles and platforms. It is powered off of two power supplies of anaywhere from 24v to 48v each up to 6amps @ 24v.  The aluminum enclosure is rated to 3000m depth - derate appropriately for human ocupancy vehicles.

### ISMS Vechicle Placement

ISMS-Diagram-Vehicle-Layout

<center><b>Typical ISMS Layout on an ROV or Sub</b></center>

ISMS can be deployed on vehicles or landers in any orientation. Typically it will be placed towards the aft or sides of the vehicle where there is mounting space available and fluid is drawn via a flexible tubing from the Stainless or Ti sampling wand and heat exchanger at the front of the vehicle where manipulators may be located to the ISMS and external components mounted at the rear.  **Note**: the heat exchanger (and high temperature sampling wand) are only required when there is an expected temperature difference between the sampled fluid and the surrounding environment, such as when sampling hydrothermal vent fluids.

### System Overview

ISMS-Diagram-System-Overview

<center><b>External components of the ISMS</b></center>

A standard ISMS setup consists of the main instrument bottle with several external components connected by a flexible plastic fluid line as well as a branching power/data cable. The sampling fluid (typically seawater) is sucked in at the sampling wand, brought to local ambient temperature by a short heat exchanger, past the membrane inlet which separates from the liquid water  gases and volatile compounds to be measured by the mass spectrometer. After the membrane inlet, the sampled water continues through the fluid pump and passes through an optional pH probe before being expelled back into the environment. Communication with and power for the ISMS (including external components) are handled through a single 8-pin subconn connector.

### Cable Connections

 [SubCon Octopus Cable Key.pdf](<Wiring/SubCon Octopus Cable Key.pdf>)

The ISMS main bottle is connected to the external components as well as vehicle/topside communication and power through a branched "octopus" cable with Macartney subconn terminations. The main ISMS exposes a 16-pin male subconn bulkhead which connects to the octopus cable. Each end of the octopus cable has a unique number of pins and colored sleeve indicating the matching external component it attaches to. The black 8 pin connector on the Octopus cable is the topside/vechicle connection and the wires should be routed to the operator at the surface, in the sub, or to your own control board on autonomous landers/platforms/AUVs. The other two external subconn connectors on the "Octopus" cable go to the fluid Pump and optional pH probe (either pyroscience aquapHOX-LX/TX or external waterproofed pico-ph-sub probe)

The 8-pin subconn "Topside/Vehicle" connector consists of two RS232 serial connections - one for interacting with the ISMS main control board and another for directly communicating with and reading data from the onboard Residual Gas Analyzer (Mass Spectrometer). Power is supplied through two separate power inputs within the 8-pin subconn each supporting power input between 24 & 48 volts.

The RGA serial connection requires a special "Fake Handshake" DB9 connector between the cable and Laptop or USB to RS232 converter. This cable is documented in the fabrication wiring section of this documentation and should be provided.

**The recommended topside wiring is shown below:**
> For more details see the topside section of the [Wiring Guide](Wiring/README.md)

ISMS Recommended Topside Wiring

### Commisionining and Troubleshooting

For additional guidance read the [User Guide](<../Operation/User Guide - In-Situ Mass Spectrometer V3.md>) and [Troubleshooting Guide](<../Operation//Troubleshooting Guide - In-Situ Mass Spectrometer V3.md>)

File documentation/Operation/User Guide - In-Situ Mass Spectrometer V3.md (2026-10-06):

<b style="color:#9b0000; font-size: 1.7rem">User Guide</b>

# In-Situ Mass Spectrometer V3

Header-Image

## System Overview

External-Component-Connections-Overview

<center><b>External components of the ISMS</b></center>

A standard ISMS setup consists of the main instrument bottle with several external components connected by a flexible plastic fluid line as well as a branching power/data cable. The sampling fluid (typically seawater) is sucked in at the sampling wand, brought to local ambient temperature by an optional short heat exchanger, past the membrane inlet. The membrane is selectively permiable to gases and volatiles while excluding the liquid water. These gases enter the vacuum chamber to be measured by the internal quad pole mass spectrometer. Once flowed past the membrane inlet, the sampled water continues through the fluid pump and passes through an optional pH probe before being expelled back into the environment. Communication with and power for the ISMS are handled through a single 8-pin subconn connector with two RS232 serial connections \- one for interacting with the ISMS main control board and another for directly communicating with and reading data from the onboard Residual Gas Analyzer (Mass Spectrometer). Power is supplied through two separate power inputs within the 8-pin subconn each supporting power input between 24 & 48 volts.

## Vehicle Setup

See the [ISMS V3 Vehicle Integration Guide.md](<../Fabrication/ISMS V3 Vehicle Integration Guide.md>)
Recommended-Vehicle-Layout
<center><b>Typical ISMS layout on a vehicle deployment</b></center>

## Operation

When running the ISMS on the bench and at sea there are is a common set of steps to run the instrument, take measurements, and properly shut down the instrument.

1. Locate the 8-pin subconn connector from the ISMS cable or the pass-through vehicle connections that connect to the ISMS.
   1. On the bench or where the 8-pins subconn is accessible, connect the included splitter cable to the subconn which should provide two power inputs as well as two DB9 connectors \- one for the ISMS serial connection and another for the internal RGA connection (which has the “special handshake” cable end).
2. Connect the DB9 RS232 plug from the ISMS labeled “**ISMS Main Serial**” to your computer via the provided RS232 to usb adapter cables.
3. Open serial studio (or termite/putty/etc) window and check which port appears when clicking the port selection dropdown when the usb adapter cable is plugged into the computer USB port (on Windows they will look like COMx and on mac/linux they will look like cu.usbserial-xxx) \- you may need to close and reopen the menu to update the list of connected serial ports \- more on how to use serial studio is found in the next section.
4. Connect the other DB9 RS232 plug from the ISMS labeled “**ISMS RGA Serial**” to your computer via an RS232 to usb adapter cable.
5. Connect a 24 or 48 volt power supply that can handle up to 7 amps at 24v to both of the power inputs (alternatively connect two separate power supplies that can handle 4 amps to each of the power inputs)
   1. If the vehicle provides power, turn on the relevant power switches,
6. One serial studio window should show “Waiting for startup…” followed by several boot messages, while the other may show gibberish or nothing.
   1. If neither serial connection shows anything, insert “null modem” adapters between BOTH DB9 plugs \- swapping tx and rx is a common source of error.
7. Open the SRS RGASoft software (Download [here](https://www.thinksrs.com/downloads/soft.html)) and choose the RGA which should appear on the other serial port.
8. Use the next section to Setup the serial studio dashboard for using the ISMS in a nicer way. (This is optional as all the system information is readable via the raw serial console.)
9. Startup the ISMS by either clicking on “Startup All” in Serial Studio or sending the command “STARTUP” (without quotes) to the **ISMS Main Serial** connection.
   1. This will start the roughing pump & fluid pumps first and then start the turbo pumps 1 minute later, alternatively start the pumps manually by sending “ROUGHING ON” and “FLUIDPUMP ON” followed by “TURBO ON” after at least 30 seconds wait.
10. Watch the turbo ramp up time and current \- it should only take at most 40 seconds and have peak current about 4.3 amps, if longer times or higher currents are seen this could indicate a slow leak \- turn off turbo and try leaving the roughing pump on longer before enabling the turbo \- see troubleshooting guide.
    1. It’s a good idea to leave the roughing and turbo pump running with the inlet capped for at least 30 minutes before deploying and 24 hours if the internal vacuum chamber was opened to ensure residual moisture and volatiles that may have stuck to the chamber walls are flushed before sampling the target fluid.

### Shutdown

1. First stop the current scan in the SRS RGA software and **turn off the filament** by going to toolbar > probe menu \> turn off filament.
2. Turn off the turbo pump motor in Serial Studio (Serial command: `TURBO OFF`) and wait for it to spin down which **may take up to 25 minutes.**
3. Unplug/disable power input to the ISMS
4. Click disconnect in Serial Studio and unplug serial connections.

## Serial Studio Dashboard

ISMS v3 has a visual dashboard that utilizes the free Serial Studio software found here: [https://serial-studio.com](https://serial-studio.com/)

Download the project file from [here](https://github.com/Girguis-Lab/In-Situ-Mass-Spec/blob/ifremer-2026-build/Ifremer-isms-documentation/Ifremer%20Modern%20ISMS%20Serial%20Studio%20Dashboard.ssproj) and open it in Serial Studio.

Serial-Studio-Connection

1. Choose data export options to record the system data while the instrument is running.
   \-\> CSV Spreadsheet and Console export options are recommended.
2. Select the COM port for the ISMS with the shown options.
3. Hit connect in the upper right \-\> If the com port is correct, The ISMS will restart and you will see “Waiting for startup…” followed by more lines and the dashboard will open. If you see garbled messages, nothing, or data is not updating try a different com port, ensure serial parameters are as shown or try adding a null modem plug to the RS232 lines \- RX & TX get swapped all the time.

Serial-Studio-ISMS-View

The dashboard should look like this \- if the raw console opens in a new window, you can close it.

Serial-Studio-Console-Button

At the top are action buttons for controlling the ISMS:

Serial-Studio-ISMS-Action-Bar

| In the bottom left corner are any active warnings coming from the ISMS as well as utility buttons such as to open the raw serial console, a stopwatch, a play/pause control for the incoming data, etc… | In the lower right corner you can choose different views of the data such as plots or the default overview. |
| :--- | :--- |
| Serial-Studio-Botom-Bar | Serial-Studio-View-Selection |

To access the command line interface of the ISMS, use the console button. Commands can be typed in the box at the bottom and the output will be displayed on the console.

Serial-Studio-Console-Button

## Command Line Interface

Commands are case insensitive, and use underscores for the command and space between the command and argument(s)

### Standard Commands

**HELP** *DEBUG (optional)*

* **Example:** `HELP DEBUG`
  Shows a help message; add DEBUG to show additional troubleshooting commands.

**BEAT**

* **Example:** `BEAT`
  Send BEAT to stop autostart for this boot cycle; used to temporarily enforce fully manual control.

**STARTUP**

* **Example:** `STARTUP`
  Run full auto startup sequence.

**ROUGHING** *ON|OFF*

* **Example:** `ROUGHING ON`
  Turn the roughing pump power on or off.

**CRYO** *ON|OFF*

* **Example:** `CRYO OFF`
  Turn the cryotrap power on or off.

**FLUIDPUMP** *ON|OFF*

* **Example:** `FLUIDPUMP ON`
  Turn the fluid pump power on or off.

**FLUIDPUMP\_RATE** *\-100-100*

* **Example:** `FLUIDPUMP_RATE -50`
  Sets the fluid pumping rate as a percentage of full speed. Negative values run the pump in reverse. 0 will turn off pump power.

**TURBO** *ON|OFF*

* **Example:** `TURBO ON`
  Power ON/OFF turbo pump at configured speed.

**TURBO\_SPEED** *0.0-100.0*

* **Example:** `TURBO_SPEED 75.0`
  Sets the turbo pump to run at a target speed as percent of max speed (100% is 90,000 RPM for the Pfeiffer TC80). Send 0 to reset to Pfeiffer default speed control mode.

**TURBO\_LIMIT\_PWR** *0-100*

* **Example:** `TURBO_LIMIT_PWR 60`
  Sets the turbo pump power limit as a percentage of full power (Pfeiffer max draw is 5A).

**TURBO\_CLEAR\_ERRORS**

* **Example:** `TURBO_CLEAR_ERRORS`
  Clears turbo pump errors and warning messages.

**STATS\_INTERVAL** *MS|OFF*

* **Example:** `STATS_INTERVAL 1000`
  Sets how often the system broadcasts stats to topside serial in milliseconds. Send OFF to disable stats logging.

**SET\_AUTOSTART** *ON|OFF|DELAY*

* **Example:** `SET_AUTOSTART 5000`
  Set whether the system should startup automatically. If an integer is passed, it is the delay in milliseconds after boot when the automatic startup routine will begin (unless the  BEAT command is sent beforehand).

### Troubleshooting Commands

**VERSION**

* **Example:** `VERSION`
  Prints firmware version.

**PINOUT**

* **Example:** `PINOUT`
  Prints configured Arduino pinout and I2C/RS485 addresses.

**DEBUG\_LOGGING** *OFF|LOW|HIGH*

* **Example:** `DEBUG_LOGGING HIGH`
  Enable additional logging to serial for troubleshooting purposes.

**RESET\_SETTINGS**

* **Example:** `RESET_SETTINGS`
  Resets settings saved on the ISMS to their default values (does not change TURBO pump or RGA parameters, which are saved within their respective instrument).

**TURBO\_RESET**

* **Example:** `TURBO_RESET`
  Resets turbo pump parameters for default operation in normal conditions (light gases, default speed control mode, power limit 100%). Use this if the turbo is misbehaving.

**TURBO\_QUERY** *PARAMETER\_NUMBER*

* **Example:** `TURBO_QUERY 398`
  Query a parameter from the turbo pump with the 3-digit parameter number. See TC80 Manual Page

**TURBO\_CMD** *PARAM DATA*

* **Example:** `TURBO_CMD 702 00123`
  Send a command to the turbo pump with the 3-digit parameter number and optional data string.

**TURBO\_RAW** *COMMAND*

* **Example:** `TURBO_RAW 0010039802=?115`
  Send raw ASCII to the turbo pump. See

**GPIO** *PIN\_NUMBER ON|OFF*

* **Example:** `GPIO 13 ON`
  Set any Arduino pin high or low – TESTING ONLY, potentially dangerous.

### Output Format

The modern code serial outputs follow a consistent pattern:

* Lines starting with  `+`    |     `->`  or  `<-`   are responses from the ISMS that can be ignored by system stats parsing code.
* Lines starting with  `->`  are messages sent to the Turbo Pump (When logging ≥ debug)
* Lines starting with  `<-`  are responses from the Turbo Pump (When logging ≥ debug)
* Lines starting with    `!`    are warnings or errors.

Other lines are the system status update that is sent periodically and follows a key-value pair format:

`Fluidpump_Rate:-50%,Turbo_RPM_Setpoint:90000,Turbo_RPM:32000(!),
Turbo_Current:4.40A(!),Turbo_Rotor_Temp:21C,Turbo_Elec_Temp:28C,
Turbo_Bottom_Temp:21C,Roughing_on:1,Fluidpump_on:1,Cryo_on:0`

* Keys and values are separated by a colon, and each pair is separated by comma.
* Values are always numeric but may start with minus and end in a unit and/or the characters (\!) which indicate that the value is outside of the expected range of normal operation. Note that the (\!) is expected to appear while the instrument is pumping out or while the instrument is spinning down.
* Values for Roughing\_on, Fluidpump\_on, and Cryo\_on indicate if that component is powered where 0 indicates OFF and 1 indicates ON

* If the instrument is interrupted while polling sensors and sending this line, it will print ,TRUNICATED after the last valid field.

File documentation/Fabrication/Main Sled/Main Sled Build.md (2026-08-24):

# Main Sled Build

The ISMS is built onto a sled that slides into the main housing and is attached to the housing endcap with the inlet and other ports.

### Assembling Inlet

Parts required:

- Inlet Base (Ti)
- Inlet cap (Ti)
- Frit
- Membrane Material (backed teflon or mesh reinforced PDMS)

Tools Requried:

* 16mm or 5/8" hollow cuttout tool and hard teflon "cutting board"
* Hammer or cutting press.

Cut out a disk from the membrane using the cutout tool (or laser cutter for PDMS composite membranes - ask kyle for laser cutter settings used>)

p00001

Screw the 1/4" NPT to Swagelok 1/4 tube fittings into the inlet top cap fluid ports with ~2 wraps of standard PTFE pipe wrap tape on each fitting.

p00002

Lightly grease o-rings and Add to their respective grooves (o-ring sizes smallest to largest:  TODO fill in )

Add frit in center of inlet base, taking note of any bevel on the edge of the frit, which should go DOWN if present so the surface of the frit and machined base surface (shown in blue) are as flush as possible.

p00002A

Another view of this step^

p00003

SideView-Inlet

Sandwich the Membrane on top of the frit - centered so it does not touch the greased o-rings - it should extend past the edges of the frit slightly. Holding the inlet cap above the base - align the screws and begin tightening - the grease of the smallest inner o-ring should allow it to cling to the groove in the underside of the cap. When you have the screws aligned and partially screwed in - slide down the cap onto the base checking that all o-rings stay centered in the groves and not pinched - in this way the smallest o-ring should be centered on the membrane without shifting.

p00004

Screw the BSPP to 1/8" tubing (yorlock brand) fiting into the vacuum side port and tighten so the rubber gasket makes a good seal.

> [!IMPORTANT]
>
> Since this side will be part of the vacuum chamber, wear gloves and avoid getting any residues on the interior of the inlet or fittings, also do NOT use Teflon tape as this is not a tappered NPT fitting.

p00005

Cut a roughly 101mm length of the PEEK plastic 1/8" OD tubing - this will serve as electrical isolation between the internal sled/vacuum chamber ground and the metal of the inlet/main housing/ocean. This isolation is nescesary for some host sub vehicles to detect electrical problems.

p00006

Connect the PEEK tubing to the inlet adapter fitting using brass swagelok ferrules (brass or stainless steel nut is ok and Yorlock is cross compatible with swagelok components/ferrules) 

> [!IMPORTANT]
>
> While 1/8" swagelok/yorlock fittings should be tightened 3/4" turn past "finger tight" (See [Swagelok Fitting Installation](https://stavanger.swagelok.com/en/resources/tube-fitting-installation)), PEEK tubing is especially fragile, so err on the side of less tight and tighten as needed once you are able to test the capped vacuum performance. Replace if overtightened or visibly strained and try again with new brass ferrules - the brass is slightly softer than stainless ferules so that should help with over-tightening.

### Assembling Primary Housing Endcap

p00001

Screw in prevco dual seal vent plug ensuring both o-rings are present and lightly greased.

p00002

Screw in zincoid sacrificial anode (Do not use tef-gel or other insulating material between anode and endcap threads as this defeats the purpose)

p00003Screw in subcon 16pin male bulkhead with red FEMALE locking sleve (not the male variant pictured here) and dummy plug.

p00004

Apply teff-Gel to the surfaces marked in teal  (but not inside the o-ring grooves) to prevent galvanic corrosion/electron exchange between the inlet base and the main enclosure end cap while in seawater.

p00005

Add lightly greased o-rings to inlet avoiding getting tef-gel on the o-rings.

p00006

Apply a generous amount of teff-Gel to the threads of the 1/4-20 x 1" bolts with washers and affix to main end cap, making sure tubing ports are facing in a direction suitable to route the external fluid path.

### Assembling Sled Chassis

Machined Parts required:

- 4x rails (Machined brass>)
- 1x electronics base plate (Machined brass>)
- 2x center chassis spacer disks  (machined black Delrin plastic>)
- 2x end chassis spacer disks  (machined black Delrin plastic>)

p00001

p00002

p00003

The four bottom holes in the roughing pump will need to be tapped with an 10-32 thread tap to accept the screws. Apply a small amount of Swagelok VacGoop to the BSPP threads of the BSPP to YORLOK fitting and screw into inlet port of the roughing pump following BSPP fastening norms (screw till mostly tight then finish by screwing down nut over o-ring flange>)

p00004

p00005

p00006

p00007

p00008

p00009

Screw in terminal blocks to laser cut mounting plate with M2.5 x 16mm screws and lock nuts, then ziptie plate to rails centered over the large flange of the turbo pump. The terminal slot marked "1" on the laser cut mount plate should be on the left side in this photo.

p00010

Attach main end cap with 5 screws to the end ring (Note how these screws screw INTO the endcap from the backside of the end ring).

p00011

Completed sled.

### Connecting Inlet to Vacuum

As of writing this part was the least settled. Two options exist: 

- A) Add a lenth of small diameter capilary tubing between the inlet and vacuum chamber to reduce the total gas load on the RGA and hopefully achive tighter mass spectra peeks
- B) Go straight from inlet to vacuum chamber side port 

In either case, the length of PEEK tubing that provides electrical insulation must still be there along with a union Swagelok tube fitting to connect the PEEK tubing to the capilary or a length of stainless tubin that can take a tighter bend than the pure PEEK tubing to go into the vacuum chamber side port.

Option A Shown here:

Option A

> [!TIP]
>
> Cap the vacuum chamber for now at the side port using a swagelok fitting plug. Once you have established that the capped vacuum is tight, then go back and finnish installing this connection

## Next build section: [Wiring](<../Wiring/Wiring Guide.md>)

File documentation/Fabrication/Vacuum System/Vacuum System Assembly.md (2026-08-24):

# Vacuum System Assembly

**Parts required:**

- See vacuum parts list section in main parts spreadsheet.

### Unpacking Components

s0

If already installed, remove the RGA electronics enclosure from the Quadropole tube by unscrewing the long body screws and sliding/pulling the case back firmly.

s1

If the turbopump has a small DIN flange attached to the outlet port, unscrew it using a wrench on the flat sides.

### Assembling the Vacuum Stackup

While assembling the vacuum components, make sure your work area is relatively dust/residue free, wear fresh gloves, and avoid touching inner surfaces that will be exposed to vacuum where possible.

> [!tip]
>
> Have a sturdy chemistry lab stand with a flask clamp, affixed to the table you're working on to provide a second grip to keep the vacuum stack upright as it grows.

> [!IMPORTANT]
> ALWAYS USE FRESH COPPER GASKETS whenever you must open, re-tighten or re-assemble any vacuum flanges!!

s2

With the turbo pump upright, lay a fresh copper gasket on the circular "kife edge" followed by the 2.75" to 4.5" Conflat flange adapter and align the holes.

s3

Screw together with the silver plated 5/16-24 x 2.00" bolts untill just snug, but don't tighten yet! Use Nordlock/wedgelock washers on the back side between nuts and bolt holes. Do not use washers on the bolt head side since the bolt head flare already distributes the load.

> [!NOTE]
>
> The silver plating on the bolts serves two important functions: It lubricates the bolts and provides a dissimilar metal to prevent galling without the need for lubricants which may off-gas and contaminate the mass spec signal.

s4

Stack the rest of the vacuum chamber components into a small tower, each with a fresh 2.75" CFF copper gasket. Pay attention to the alignment of several key features: The turbo pump control box and side port on the second small flange facing the front side, while the two long alignment pins on the RGA quad tube are towards the back in this illustration. Lower the quad tube gently to avoid hitting the cage on the inside of the vacuum flanges.

s5

Screw together till finger-snug using the silver plated 1/4-28 X 2-1/2" bolts that were order along with a Stainless steel normal washer.

### Tightening Bolts

s6B

Once you are satisfied that everything is properly rotated and aligned, use the fixed lab stand mentioned earlier to hold the Quadropole tube and keep everything steady

s6

while tightening all the bolts we've installed so far (so both the bolts in the 4.5" CF flange and 2.75" CF flanges).

When tightening conflat flanges, tighten every other bolt in an alternating pattern. Use a long wrench or wench extension to get maximum leverage. When done right you should be able to keep tightening each set of bolts past where they used to feel stuck many times - this is the copper gaskets deforming under the stress - which is what we want to get a perfect seal. A fully tightened conflat flange pair should have a gap only slightly larger than a sheet of paper- You'll know you are done when you physically can't tighten ANY of the bolts with a long wrench.

> [!TIP]
>
> To gain leverage on the turbo pump without scratching it, lay a second small wrench between the star bolt heads on the 4.5" base so the wrench handle/bar gets stuck between the boltheads and the conflat flange outer surfaces and allows you to put torque on it.

### Adding Tube Fittings

s7

Spread a small amount of swagelok VAC Goop on the BSPP threads of the BSPP to 1/4" Yorlock tubing fitting to prevent galling.

Twist BSPP threads into the port until close to the right angle, then finger tighten the loose nut down onto the fitting to seal temporally.

> [!IMPORTANT]
>
> BSPP, yorlock tube, and swagelok tube are not tappered thread fittings, so DON'T USE PTFE TAPE / "TEFLON" TAPE on these threads - it won't help with sealing and could hurt it.

s8

Note for future steps: The bspp fitting is angled slightly down to accommodate the tubing run. Get it roughly aligned now, with the idea that you'll need to loosen the lower nut and get the angle exact when you install the tubing run shown in orange later.

s9

Screw the in the 1/8" NPT to 1/8" swagelock tube fitting into the side port. Wrap with 2-4 wraps of teflon tape. You may need to play with the number of wraps to get the angle right.

> [!IMPORTANT]
>
> When working with NPT fittings, always use 2 or more wraps of standard thickness Teflon/PTFE tape (or slightly less with 'stainless steel' rated PTFE tape). The biggest risk is getting bits of teflon tape inside the vacuum chamber which can fly into the turbo pump and jam or dent the blades. SO, make sure the teflon tape wrap doesn't extend past the last screw thread, and that you clean the inner and outer threads after removing teflon-taped fitting with a pick before re-inserting a new fitting with new teflon tape. Orient the chamber down so any tape bits don't fall into the vacuum chamber while cleaning it.

### Final RGA Assembly

s10

s11

Lastly slide the RGA Electronics box over the pins and tighten using the long screws that run from the back of the RGA electronics box.

### Bending Vacuum Tubing Run

Parts & tools required:

- 1/4" OD x  Stainless steel continuous straight tubing - about 4ft long.
- 1/4" tubing bend tool
- Protractor, Pen & Paper
- Clamps and a flat work surface.

These are the steps to create the tubing run that goes between the Roughing inlet and Turbo Pump outlet shown here: https://cad.onshape.com/documents/b6c7e603ca3691b93cbc85d9/w/9ed404cfa2f2ee86ebc2e394/e/7f697bb443b9acb569f2a20e

1. Starting from one end of the tube, mark off the following distances (all relative to your 'start' end of the tube)

   | **Distance from start** | **Bend amount AFTER each mark**                              |
   | ----------------------- | ------------------------------------------------------------ |
   | 82mm                    | 15° - PLANE A                                                |
   | 139mm                   | -15° - PLANE A                                               |
   | 186mm                   | 8.43° - PLANE B (PLANE B is perpendicular to PLANE A, Rotated 90° along the axis of the tube) |
   | 332mm                   | 45° - PLANE B                                                |
   | 395mm                   | -90° - PLANE B                                               |
   | 460mm                   | 90° - PLANE B                                                |
   | 526mm                   | -90° - PLANE B                                               |
   | 600mm                   | 45° - PLANE B                                                |
   | 659mm                   | 90° - PLANE C - (perpendicular to both plane A & B; axially rotated 59° CCW relative to PLANE B (or 31° CCW relative to PLANE A)) |
   | 764mm                   | -90° - PLANE C                                               |
   | 807mm                   | END CUT                                                      |

Step1

Bends 1 & 2:

Step2&3

Bend 3 (Clamping):

Step4A (./Images/Tubing Bending Steps/Step4A (Clamp).jpeg)

Bend 3 (Jig):

Step4B (./Images/Tubing Bending Steps/Step4B (Jig).jpeg)

Bend 3 (Actual Bend):

Step4C (./Images/Tubing Bending Steps/Step4C (Bend).jpeg)

Bend 4:

Step5

Bend 4 (Finished):

Step5 (./Images/Tubing Bending Steps/Step5 (Finished).jpeg)

Bend 5 (Finished):

Step6 (./Images/Tubing Bending Steps/Step6 (finished).jpeg)

Bend 6:

Step7

Bend 7 (finished):

Step8(./Images/Tubing Bending Steps/Step8(finished).jpeg)

Bend 8 (finished):

Step9(./Images/Tubing Bending Steps/Step9(finished).jpeg)

Bend 9 (Compound Angle setup):

Step10A(./Images/Tubing Bending Steps/Step10A(Compound Angle).jpeg)

Bend 9 (Compound Angle, actual 90* bend):

Step10B(./Images/Tubing Bending Steps/Step10B(CompoundAngle).jpeg)

Bend 10:

Step10(./Images/Tubing Bending Steps/Step10(finished).jpeg)

Bend 10 (another view):

Step11

End Cut:

Step12(./Images/Tubing Bending Steps/Step12(end cut).jpeg)

All done! We'll install it between the two vacuum pumps after the sled is assembled.

## Next build section: [Main Sled Build](<../Main Sled/Main Sled Build.md>)

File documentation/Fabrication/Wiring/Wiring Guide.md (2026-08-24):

## Internal Wiring

### Cut Wires

Cut the following sections of 24 AWG Silicone wire (or other flexible, stranded wire):

**RGA Power Wires** - 6 inches (5.5in once twisted together)

*Connectors: 2pin vertical female Microfit 3.0 | 5.5mm x 2.1mm center+ locking barrel plug  (Provided w RGA)*

- Black
- Red

**RGA Serial Wires** - 26.5 inches (24.75in once twisted together)

*Connector: Male DB9 with hood - fake handshake wiring will be added*

- Black
- Blue
- White with Black stripe

**Roughing Pump Power Wires** - 14.5 inches (13.5in once twisted together)

- Red
- Black

**Turbo Pump Power & Serial Wires** - 17.75 inches (16.5in once twisted together)

- Red
- Black
- Brown
- Orange

**Topside Power & Serial Wires** - 28.4 inches (26.5in once twisted together)

- Black
- White
- Red
- Green
- Orange
- Red with Black stripe

**Fluid Pump Wires** - 13 inches (12.25in once twisted together)

- Green with Black stripe
- Orange with Black stripe
- Blue with Black stripe
- Black with White stripe

**Fluid Pump Direction Control Add-on Wires**

- Yellow - 13.5 inches (not twisted>)
- 6x yellow solid core wire - 1.75 inches

**pH probe wires** (optional) - 15.5 inches (14.5in once twisted together)

- Red with White stripe
- Green with White stripe
- Blue with White Stripe
- Black with Red Stripe

Twist or braid wires into cables so they form nice bundles like so - a shortcut to do this is to leave some extra wire at one end to insert in the jaws of a power drill on low speed, with the other end clamped, then cut off the part that got mangled in the jaws once twisted sufficiently. Best practice would be to center the ground conductor in the larger cable bundles, but this is not necessary for the short distances involved:

WiringTwistExamples

### Adding Connectors

All connectors on either end of the Main PCB are molex Microfit 3.0 female connectors consisting of pin sockets which must be crimped and inserted into connector bodies of various pin count.

Crimping molex pins and sockets is fairly simple, but there are many things to keep in mind to ensure a solid connection, with proper strip length, that doesn't bend parts of the connnector that should stay straight. Watch these videos to learn how to crimp: https://www.youtube.com/watch?v=pTJ77xNArZA & https://www.youtube.com/watch?v=2CHQWd-844Y and keep in mind the molex guidelines on page 17 of this guide https://tools.molex.com/pdm_docs/ats/TM-638000029.pdf

Gold plated connectors are recommended as these have slightly more durability. Even still keep plugging/unplugging to a minimum - many connectors are only rated to 10's of plug/unplug cycles.

#### Main PCB Connections

Create pigtails (connector at one end with bare ends at the other) for each used connector on the PCB.

Follow the wire color pin order to make each connector pigtail. Color coding is shown in the "ISMS PCB Pinouts Annotated.png" file (embedded below). The wire color coding for each connector pin is shown below the label in the corresponding pin location as a line.

ISMS PCB Pinouts Annotated

#####

##### pH Probe Connection (UNUSED):

	4x1 PIN female Microfit 3.0

Currently the pH probe is not connected because we are using a standalone pH logger (PyroScience AquapHOx-LX) that doesn't need power or data. Theoretically realtime data can be got from the AquapHOx-LX, but it requires a USB host intermediary like a raspberry pi to read the serial data (format found in the [protocol docs]) if wired per the USB output wires shown here: AquapHOx-LX Subconn Pinout

##### RGA Power:

	2x1 PIN vertical female Microfit 3.0

##### Turbo Pump Power & Serial Wires:

	2x2 PIN female Microfit 3.0

##### Topside Power + Console:

	 3x2 PIN female Microfit 3.0

##### Custom Fluid Pump:

	3x1 PIN female Microfit 3.0

##### Roughing Pump Power:

	2x1 horizontal female Microfit 3.0

##### Extra Digital Pins

	1x6 PIN male & female Microfit 3.0 connector

(used for adding direction forward/reverse control to Fluid Pump):

Solder 6 short connections from the PCB to a free-floating 6 pin male Microfit 3.0 connector and another to the yellow wire on pin 1 as shown here at the bottom of the photo. The 6 pin setup is to allow future expansion and structural integrity.

ExtraDigitalPinsWiring

##### Extra Power Taps (UNUSED):

 5x2 PIN female Microfit 3.0

##### ICSP Headers (X2, BOOTLOADER TROUBLESHOOTING ONLY):

3x2 standard 2.54mm pitch pin header (not Molex>)

#### Other Connectors

##### RGA Power Plug

- **Side A (Already Done):** 2pin vertical female Microfit 3.0

- **Side B:** 5.5mm x 2.1mm center+ locking barrel plug  (Provided w RGA)*

  - Solder connector like so: https://electronics.stackexchange.com/questions/77671/how-to-solder-wires-on-to-this-power-barrel-plug. Use Heat shrink to insulate inner contact. When installing, the tabs on this barrel plug twist lock into the RGA body - Do not force it in or out!

  RGA Power Connector Internals

##### RGA Serial Connection

Does not go through PCB, instead it goes directly to terminal block and out of main housing up tether or to vehicle

RGA Serial DB9 Wiring - RGA Connector

RGA DB9 Connector Internals

##### **Roughing Pump Power**

The roughing pump uses a male DB15 plug and also requires some jumpers behind the connector that tell the roughing pump to start up inmediately once power is supplied. See page 23 of the [roughing pump manual](<../../Operation/Component Manuals/Roughing Pump Manual pfeiffer_mvp_010_3_dc.pdf) for an explanation of this wiring.

Roughing Pump Power DB15 Wiring

Roughing Pump DB15 Connector Internals

##### Turbo Pump Connector

The Turbo Pump connector is simpler but follows a similar pinout as the roughing pump. See the turbo pump TC80 controller manual page 18 for an explanation of pinout:   [Turbo Pump Control Unit Manual Pfeiffer-TC-80_Operating-Instructions.pdf](<../../Operation/Component Manuals/Turbo Pump Control Unit Manual Pfeiffer-TC-80_Operating-Instructions.pdf)

Turbo Pump DB15 Wiring

Turbo Pump DB15 Connector Internals

### Wire Routing

Recommended wiring routing layout using zipties

WireRoutingTopView

Roughing pump power cable is tucked underneath lower rail and held with black zipties:

WireRoutingSideView

The terminal block plate sits over the turbo pump and connects the 16pin subconn external connection wires to the isms internals. The mounting plate should be laser cut & engraved from 1/4" thick accrylic using the file: [Terminal Block Mounting Plate Laser Cut.eps](<Laser Cut Designs/Terminal Block Mounting Plate Laser Cut.eps) Every wire from the 16 pin external connection matches the color of the corresponding wire internally except for the fluid pump forward/reverse wire, which is the only yellow wire in the system and connects to the black wire with white stripe in position 12 on the terminal blocks (and 16 pin subconn).

Terminal Block Plate Wiring

Note that the pH probe connections remain empty due to the afformentioned lack of need for power or communication with the aquapHOx LX pH logger. If a non-standalone pH probe is added in the future these wires can be used for that (or another accesory like a cryopump). They would connect to the pH probe power and serial plug on the PCB shown in [ISMS PCB Pinouts Annotated.png](<./Build Images/Internal/ISMS PCB Pinouts Annotated.png) (assuming the pH probe was 5v powered and used ttl serial communication>)

## Topside Wiring

For now we'll ignore the wiring in between the ISMS and focus on the connectors a topside operator or vechicle needs to power and communicate with the ISMS and onboard RGA. In the next section we'll connect those connectors to something!

### Power plugs

### ISMS Comms Serial Plug

### RGA Comms Serial Plug

## External Wiring

See  [ISMS V3 SubCon Octopus Cable Key.pdf](<./ISMS V3 SubCon Octopus Cable Key.pdf>) for external connection wiring:

ISMS Octopus cable wiring diagram

TODO: finish section

### Testing with quick connectors

{TODO add photo of testing wire harness on table}

### Potting

Use the molds and putty!

## Next Build Section: [Fluid Pump](<../Fluid Pump/Fluid Pump Build.md>)

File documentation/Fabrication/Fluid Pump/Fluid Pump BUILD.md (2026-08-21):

# Oil Compensated Fluid Pump - Build Guide

Finished Fluid Pump

CAD Here: [Link](<https://cad.onshape.com/documents/9e45e871d74b8539d6687f02/w/a3384ad6c22d56b5ea88b888/e/1e5f54e24d5f977d3ebdd65c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>)

### Parts

 listed in Fluid Pump section within the overall parts list for the ISMS

3D print the following part:

- [Fluid Pump Mount - Pump Mount for BR 3- Housing.stl](<./3D Print Models/Fluid Pump Mount - Pump Mount for BR 3- Housing.stl)

Laser Cut the following parts from the 23/64" thick accrylic sheet:

-  (Optional Jig x1)  [BR end cap drilling guide jig top plate.dxf](<./Laser Cut Designs/BR end cap drilling guide jig top plate.dxf)

- (Optional Jig x1)  [BR end cap drilling guide jig bottom plate.dxf](<./Laser Cut Designs/BR end cap drilling guide jig bottom plate.dxf)

- (Optional Jig x2)  [BR end cap drilling guide jig spacer plate.dxf](<./Laser Cut Designs/BR end cap drilling guide jig spacer plate.dxf)

-  [WTE3-P-END-CAP-R1 - End Cap Plate W Diaphragm Opening.dxf](<../Laser Cut Designs/Fluid Pump/WTE3-P-END-CAP-R1 - End Cap Plate W Diaphragm Opening.dxf)

- [Fluid Pump End Cap O-Ring Groove.eps](<Laser Cut Designs/Fluid Pump End Cap O-Ring Groove.eps>)

  - Special Note: This end cap requres laser engraving or machining out the o-ring groves to a depth of approximately 1.9 mm or 3D printing the matching 3d model: [Customized_WTE3-M-END-CAP-4-HOLE-R1 - Fluid Pump End Cap plate W penetrator holes.stl](<Laser Cut Designs/Customized_WTE3-M-END-CAP-4-HOLE-R1 - Fluid Pump End Cap plate W penetrator holes.stl>)  with a watertight but durable method like SLA printing with a non-brittle resin.

    On a 75 watt Universal Systems CO2 Laser Cutter these parameters worked best - you will likely need to experiment with your laser cutter to get appropriate results before making a full cutout:

    	raster engrave settings for 1.9mm deep cut: 19% Power, 15% Speed, 1000 PPI, 0.359" z-axis height.

    See the original CAD for the desired result (end cap shown in black): https://cad.onshape.com/documents/9e45e871d74b8539d6687f02/w/a3384ad6c22d56b5ea88b888/e/1e5f54e24d5f977d3ebdd65c

### Cut the diaphragm

Cut the diaphram from the Buna-N rubber 1/8" thick sheet either with a water jet or using the jigs:

- Cut out of the rubber sheet a rough circle larger than the final shape with an exacto knife.
- Clamp the rubber circle in a stack consisting of the jig stack cut out of 1/4" thick accrylic: Drilling guide template bottom plate > Bunna Rubber sheet > Drilling guide template spacer plate (x2) > Drilling guide template top plate
- Screw together jig with 8-32 x 2" screws and nuts and clamp in a vice
- Drill holes with a 1/8" extended shank drill bit or 1/8" milling drill bit
- Cut exact outer perimeter with an Exacto knife

### Make diaphragm end cap

1. Bevel the inner edge of the Accryclic end cap plate with diaphragm opening using an exacto knife so the diaphragm will not rub against a sharp edge when expanding.
2. Sandwich the diaphragm against the Blue Robotics black aluminum end cap flange along with the face seal o-ring included w the blue robotics flange using 6 m3 x 16mm screws.
   Fluid Pump Pressure Compensation Diaphgram

### Swap micropump factory case for 3D-Printed mount

Remove the micropump-provided housing by unscrewing the two screws on the pump head and firmly twist the pump head to release it from the plastic housing. Pinch and remove the grommet so the wires can come throught the port in the housing. Slide the Micropump electronics into the 3D printed mount, aligning the screw holes as shown. Re-attach the pump head and reinstall the screws holding the pump head to the electronic drive.

Micropump Mounting Sandwich

Mcropump Mounting Sandwich Screws

### Install penetrators in oposite end cap.

Assemble the WTE based on the BR guide: https://bluerobotics.com/learn/wte-vent-assembly-guide/

All penetrators should be oriented witht the nut on the inside surface and the o-ring on the outside surface of the accrylic sheet with a thin layer of molykote 111 or 44 medium grease on the o-rings

The fluid path bulkheads should be installed just like  the other bulkheads, except the o-ring fits into the groove in the acrylic not the bulkhead.

Tighten all penetratrators firmly like described in the blue robotics WTE guide

Use m3 Screws to fasten the end cap onto the flange with the face o-ring (lightly greased)

Penetrator End Cap

4. Splice electrical connections

Following the wire color chart for the external side fluid pump in the [ISMS V3 SubCon Octopus Cable Key.pdf](<../Wiring/ISMS V3 SubCon Octopus Cable Key.pdf), splice each wire from the fluid pump to the Subconn Bulkhead with individual heat shink to prevent shorts. You can unplug the wires from the pump drive electronics for soldering. Tie back the unused wires and string using heat shrink and seal with glue to avoid shorts.

Pass cable through tubing and reconnect to pump drive connector on other end. Connect pump to diapragm end cap flange screw holes with 2 M3 x 16mm screws in the pocket holes.

Wiring Splice

 Micropump Wire Join

Wire Connection

Pump Pocket Screws

### Connect fluid path tubing to Micropump

Wrap the two 90* Elbow fittings with 1/4" standard thickness (non-ss) teflon tape for 1 & 3/4 wraps each. Screw into pump inlet & outlet until each are facing straight relative to the central axis of the Blue Robotics housing. If tightening becomes difficult or is too loose at this angle, try a different number of teflon tape wraps.

Attach two 7" long sections of 1/8" OD Nylon tubing (in red color here) to the ports using swagelok nylon ferrules instead of the stainless steel ones from the fittings.

Micropump NPT Elbow Fitting Orientation

Connect to swagelok bulkheads on end cap, again swapping plastic ferrules (and/or nuts) for the stainless steel ones from the swagelok bulkheads.

Install Locking cords

### Test

Connect subconn to main ISMS bottle and test Fluid pump with water.

### Mineral Oil Fill

Fill the pump housing with oil using a vacuum fill if possible.
Vacumm connection instructions using a hand vacuum pump: https://bluerobotics.com/learn/using-the-vacuum-test-plug/#testing-the-test-setup

To do a vacuum fill you'll need a tubing, a secondary vacuum-safe sealed jar or container with two tubes to act as a oil reservoir and trap and a vacuum pump .

1. Fill the housing about 3/4 with mineral oil & then close and seal the housing.
2. Fill the trap container with enough oil to fill the remaining volume inside the housing without covering the outlet tube.

2. Connect a tube from the pressure relief valve with the red backfill adapter screwed on and the Vacuum plug in place to the oil reservoir / trap so the tube sits at the bottom in the oil in the trap.
3. Connect the other tube from the headspace of the trap to the vacuum pump.
4. Pump a vacuum in trap - which should pull a sufficient vacuum in the enclosure as well
5. wait for degassing to occur.
6. Re-pressurize the vacuum line slightly to force the oil into the enclosure with slight positive pressure so the diaphragm bows outwards .
7. Unscrew the backfill adapter to seal the oil in - some may dribble out.

Vaccum Fill Setup

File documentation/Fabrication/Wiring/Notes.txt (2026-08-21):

Twisting 3 or more 20 Gauge stranded silicone wire together yields an approximate final length of 93.3% of the straight untwisted length.

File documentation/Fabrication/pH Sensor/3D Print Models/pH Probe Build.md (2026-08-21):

# pH Probe Notes

Current design involves a fully standalone AquapHOx-LX pH meter that is correctly timestamped to the same time zone as the operator computer, so data logs can be correlated after recovery.

### Installing the AquapHOx-LX pH logger:

The AquapHOx-LX pH logger sits after the ph probe on the fuid path.

3D print the flow cell attachment for the AquapHOx-LX using a thick wall or 100% fill FDM print.

Once printed thread tap the input and output ports with a 1/8" NPT pipe tap 

Install 1/8" npt to swagelok 1/4" pipe adapters into the NPT holes we just tapped with 2 wraps of PTFE tape.

### Using the AquapHOx-LX pH meter:

See the pyroscience software documentation - use the usb-to-subconn adapter cable included w the AquapHOx-LX.

### Alternative designs:

The onboard PCB was orignally designed to be electrically pin compatible with the [Pyroscience Pico pH Sub](https://www.pyroscience.com/en/products/all-meters/pico-ph-sub) pH Probe, however this probe requires waterproofing the back end of the bulkhead part. As such, it would need aditional oil-compendsated enclosure design and subconn or integration into the main housing end cap, which was deemed to tricky while maintaining structural integrity of the main end cap at the time.

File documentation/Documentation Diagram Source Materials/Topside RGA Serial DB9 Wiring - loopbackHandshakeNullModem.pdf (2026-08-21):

## Laptop

(Female DB9 Connector)

## ISMS RGA

(Part of Subconn 8-pin)

DCD
RX
TX
DTR
Ground
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
Ground

RTS
CTS

https://www.lammertbies.nl/comm/info/rs-232-null-modem#loop

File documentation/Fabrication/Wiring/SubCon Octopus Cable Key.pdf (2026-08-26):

### ISMS V3 Octopus Cable Connection Key

ISMS Housing Side | Exterior Connection Side
Pin No. | Wire Base Color | Wire Stripe Color | Routed To | Connector SubConn | Pin Role | Pin No. | Wire Base Color | Wire Stripe Color
1 | Black | | Vehicle / Topside | MCIL8M | Main Power V+ 1 (VIN1) | 1 | Black
2 | White | | Vehicle / Topside | MCIL8M | Main Power V+ 2 (VIN2) | 2 | White
3 | Red | | Vehicle / Topside | MCIL8M | Main Power GND (VIN-) | 3 | Red
4 | Green | | Vehicle / Topside | MCIL8M | tx/rx Arduino (tx) | 4 | Green
5 | Orange | | Vehicle / Topside | MCIL8M | tx/rx Arduino (rx) | 5 | Orange
6 | Blue | | Vehicle / Topside | MCIL8M | tx/rx RGA (tx) | 6 | Blue
7 | White | Black | Vehicle / Topside | MCIL8M | tx/rx RGA (rx) | 7 | White | Black
8 | Red | Black | Vehicle / Topside | MCIL8M | Communication GND (shared) | 8 | Red | Black
9 | Green | Black | Pump Fluid | MCIL5F | Fluid Pump ￭ GND (Shared) | 1 Black
10 | Orange | Black | Pump Fluid | MCIL5F | Fluid Pump ￭ Analog (0-5 V) | 2 | White
| | | | | UNUSED Fluid Pump ￭ Tachometer
14 | Green | White | Probe PH | MCIL6F | LX: USB Data (-) TX: RS485 Data | 2 | White
15 | Blue | White | PH Probe | MCIL6F | LX/TX: pH Power V+ (+5 VDC) | 3 Red
16 | Black | Red | PH Probe | MCIL6F | LX:USB Data (+) TX: pH Analog Signal (0-3.3v) | 4 Green
N/a | N/a | N/a | PH Probe | MCIL6F | UNUSED LX: Shield TX: RS485 Data | 5 | Orange
N/a | N/a | N/a | PH Probe | MCIL6F | UNUSED pin for Compatibility | 6 | Blue
11 | Blue | Black | Fluid
Pump | MCIL5F | Fluid Pump ￭
Power (+12v) | 3 | Red
N/a | N/a | N/a | Fluid
Pump | MCIL5F

### 4 Green

12 | Black | White | Fluid
Pump | MCIL5F | Fluid Pump ￭
Fwd/Rev 0/5v | 5 | Orange
13 | Red | White | PH
Probe | MCIL6F | LX/TX: pH
Power V- (GND) | 1 | Black

Compatibility

The 8 pin vehicle/topside connector pinout is backwards compatible with vehicles that connected to prior ISMS versions. The 16 pin main bottle connector, fluid pump, and PH probe connectors ARE NOT backwards compatible.

Locking
Sleeves

All Subconn Male (MCILxM) connectors use a female locking sleeve. Conversely the Female Subconns (MCILxF) use a male locking sleeve. This gives the exposed pins a bit of protection.

pH Probe

This cable is default compatible with pyroscience aquapHOx-LX model pH logger but can be adapted to fit aquapHOx-TX or pico-ph-sub model pH sensors with an adapter cable and firmware changes. The pin role for the pH probe is specified based on how the pin would map to the connector on an aquapHOx-LX with “LX:” or aquapHOx-TX with “TX:”

### Topside / In Vehicle Connector Pinout

SubConn Connector | Pin Role | Subconn Pin No. | Wire Base Color | Wire Stripe Color | Topside Interface Connector
MCIL8F | Main Power V+ 1 (VIN1) | 1 | Black | | Bare Lead or 1x2 pin female connector (Microfit 3.0)
MCIL8F | Main Power V+ 2 (VIN2) | 2 | White | | Bare Lead or 1x2 pin female connector (Microfit 3.0)
MCIL8F | Main Power GND (VIN-) | 3 | Red | | Bare Lead or 1x2 pin female connector (Microfit 3.0)
MCIL8F | Main Comms RX (From TX pin at ISMS) | 4 | Green | | To Female DB9 Serial > RS232 to USB converter > Windows 11 Computer
MCIL8F | Main Comms TX (From RX pin at ISMS) | 5 | Orange | | To Female DB9 Serial > RS232 to USB converter > Windows 11 Computer
MCIL8F | RGA Comms RX (From TX pin at RGA) | 6 | Blue | | To Female DB9 with ‘fake-handshake’ null modem > RS232 to USB converter > Windows 11 Computer
MCIL8F | RGA Comms TX (From RX pin at RGA) | 7 | White | Black | To Female DB9 with ‘fake-handshake’ null modem > RS232 to USB converter > Windows 11 Computer
MCIL8F | Secondary GND (VIN2) Previously known as ‘Communication GND’ | 8 | Red | Black | Bare Lead or 1x2 pin female connector (Microfit 3.0)

### Octopus Cable Subcon Connectors Detail

Octopus Cable Subconn | | Sleve | Mated Device | Mating Subcon | Mating Sleve | Mating Subconn Matched Dummy
MCIL16F | | DLSA-M | ISMS Main | MCBH16M | DLSA-F | MCDC16F
MCIL8M | | MCDLS-F | AUV/SUB Connection | MCIL8F | MCDLS-M | MCDC8F
MCIL5F | | MCDLS-M | External Fluid Pump | SVS-BHC5M-M10 | MCDLS-F | MCDC5F
MCIL6F | | MCDLS-M | External PH Probe | MCBH6M (Part of PH Probe) | IN-BUILT | MCDC6F
Benchtop Subconn | ----------------------------- TOPSIDE / BENCHTOP --------------------------------------------
MCIL8F | | MCDLS-F | Topside Laptop | N/A | MCDLS-M | N/A

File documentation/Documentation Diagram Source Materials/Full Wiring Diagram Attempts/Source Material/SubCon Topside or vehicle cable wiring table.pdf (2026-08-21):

### Topside / In Vehicle Connector Pinout

SubConn Connector | Pin Role | SubConn Pin No. | Wire Base Color | Wire Stripe Color | Topside Interface Connector
MCIL8F | Main Power V+ 1 (VIN1) | 1 | Black | | Bare Lead or 2 pin connector (Microfit 3.0)
MCIL8F | Main Power V+ 2 (VIN2) | 2 | White | | Bare Lead or 2 pin connector (Microfit 3.0)
MCIL8F | Main Power GND (VIN-) | 3 | Red | | Bare Lead or 2 pin connector (Microfit 3.0)
MCIL8F | Arduino RX (Swapped from downstream TX) | 4 | Green | | To DB9 Serial > RS232 to USB converter > Computer
MCIL8F | Arduino TX (swapped from downstream RX) | 5 | Orange | | To DB9 Serial > RS232 to USB converter > Computer
MCIL8F | RGA RX (Swapped from downstream TX) | 6 | Blue | | To DB9 Serial with ‘fake-handshake’ null modem > RS232 to USB converter > Computer
MCIL8F | RGA TX (Swapped from downstream RX) | 7 | White | Black | To DB9 Serial with ‘fake-handshake’ null modem > RS232 to USB converter > Computer
MCIL8F | Communication GND (shared) | 8 | Red | Black | Bare Lead or 2 pin connector (Microfit 3.0)

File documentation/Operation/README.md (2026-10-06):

**[Operation Guide 🖹](<./User Guide - In-Situ Mass Spectrometer V3.md>)**

**[Troubleshooting Guide 🖹](<./Troubleshooting Guide - In-Situ Mass Spectrometer V3.md>)**

**[Sub-Component Manuals 🖿](<./Component Manuals>)**

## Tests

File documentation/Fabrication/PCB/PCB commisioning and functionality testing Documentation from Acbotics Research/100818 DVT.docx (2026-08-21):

# 100818 Mass Spec PCB Design Verification Testing

# Microcontroller Programming.

## Setting Fuses.

Both microcontrollers need to have their fuses (configuration bits) set. This cannot be done through MPLAB IPE, but must be done through Microchip Studio, which only runs in Windows.

Fuse Settings to Use are below:

### Atmega2560

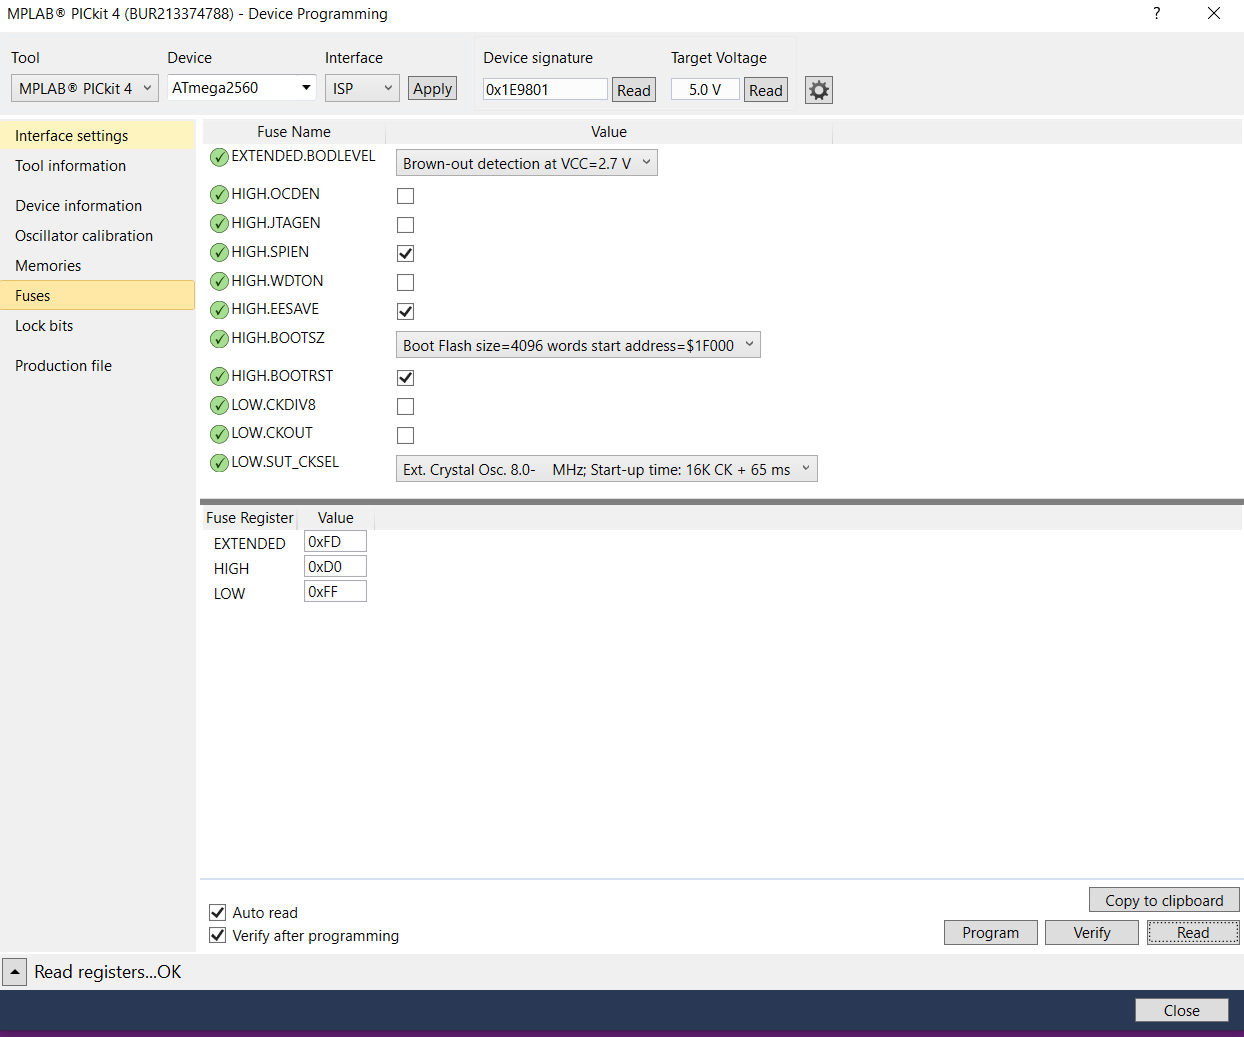
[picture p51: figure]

### Atmega16U2

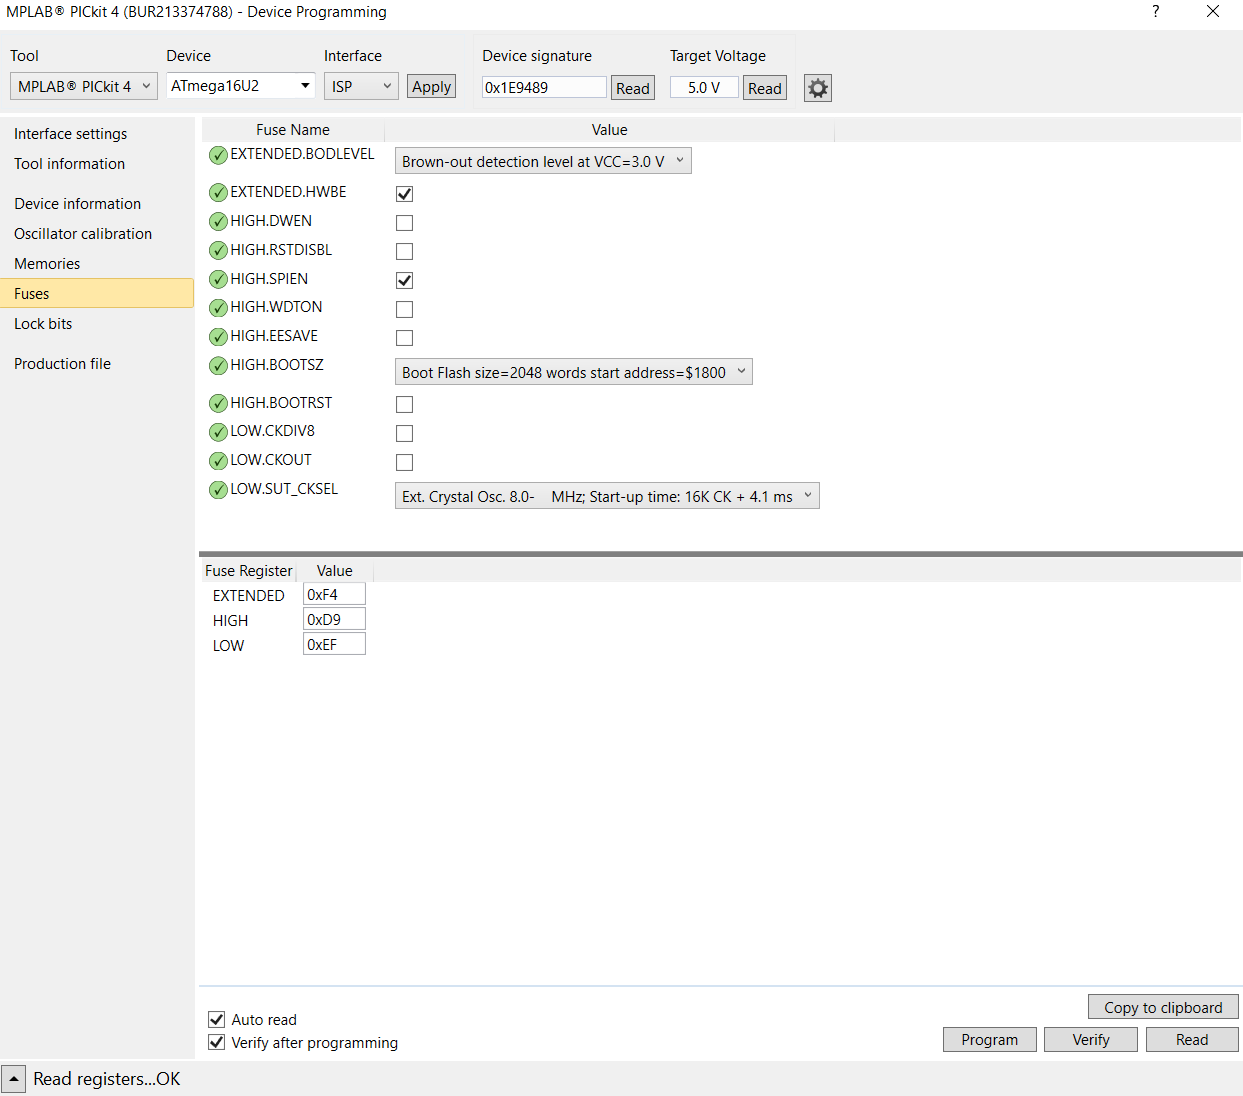
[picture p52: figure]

## Programming Firmware

ATmega16U2_read.hex

2560-blank.hex

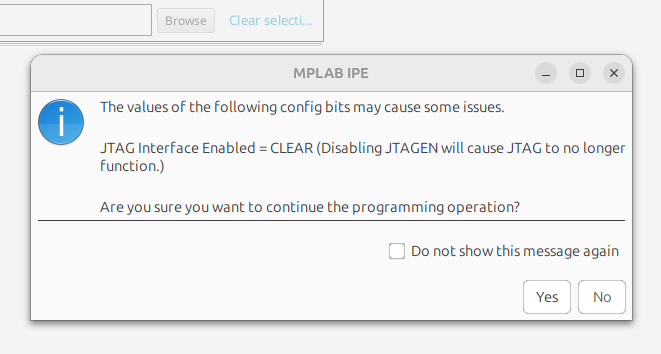
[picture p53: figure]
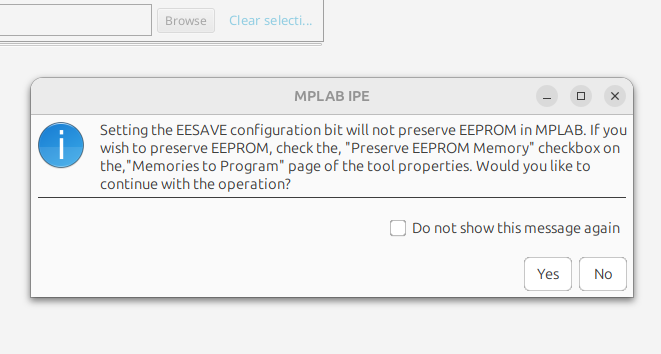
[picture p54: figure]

# Power Supply Testing

## 24V #1 @6.9A (Mass Spec and Turbo pump)

Connected Vin to 2x 30V supplies to share load.

Tested with Variable load up to 7A. Regulation maintained throughout loading.

## 24V #2 @ 2.5A (MVP)

Connected to 1X 30V supply. Soldered wire to output of regulator (bypassing switch).

Verified 24V output at 18V input and 31V input.

Verified with 2.5A load @31V.

Verified with 2.5A load @18V.

## 12V @ 500mA (CFP)

Connected to 1X 30V supply. Soldered wire to output of regulator (bypassing switch).

Verified 12V output at 500mA @18V

Verified 12V output at 500mA @31V

# Comm Port Verifications

Used attached ardiuno code to echo back the received character plus 1 (this removes the possibility of a loopback short) on485, console and pico.

Note: Pico required a 3.3v regulator to be added next to U9 in order to function properly.

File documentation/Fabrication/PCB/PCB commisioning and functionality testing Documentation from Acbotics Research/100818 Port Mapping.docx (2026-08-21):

Serial Mapping

Arduino Serial Port | Function
Serial0 | RS485
Serial1 | Console (232)
Serial2 | Pico(ttl)

GPIO Mapping

GPIO(Atmega) | GPIO (Arduino) | Function
H5 | 8 | Analog Out
A1 | 22 | RS485 Transmit Enable
A0 | 23 | RS485 Receive Enable (active low)
K0 | A8 | LED_2
K1 | A9 | LED_1
L0 | 49 | PICO_ON
B2 | 51 | MVP_ON
B0 | 53 | CFP_ON

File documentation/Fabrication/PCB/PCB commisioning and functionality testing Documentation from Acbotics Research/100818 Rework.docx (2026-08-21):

For next rev.

Add 3.3V regulator and caps (AP7313-33SRG-7 + 2x1uF caps used for the rework)

R40/R39 should be populated with 0 ohms.

R16 should be populated with 0 ohms.

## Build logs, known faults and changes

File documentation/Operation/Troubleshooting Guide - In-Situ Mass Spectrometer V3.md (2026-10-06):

<b style="color:#9b0000; font-size: 1.7rem">Troubleshooting Guide</b>

# In-Situ Mass Spectrometer V3

Header-Image

## Diagnosis

### Serial Communication Issues

* No connection to ISMS or RGA or no console text shown on startup
* Garbled text on power up or not responding correctly to commands

**See [Fixing Serial Connections](#fixing-serial-connections)**

### Disconnection Issues

* RGA live plot stops scanning or shows a flat line.
* ISMS stats stop updating, commands do not work.

**See [Fixing Disconnections](#fixing-disconnections)**

### Fluid Flow Issues

* **Prevention:** Turn off fluid pump while moving the vehicle or when in sediment rich water
* RGA signal peaks become more defined and shrink over time without reason.
* No visible evidence of flow out the fluid path exhaust tube.

**See [Fixing Fluid Flow](#fixing-fluid-flow)**

### Slow Vacuum Leaks

* RGA signal floor rises to higher than expected and/or peaks start having noticeably less definition.
* RGA total pressure goes up gradually over time.
* RGA filament temperature and power draw goes up over time
* Turbo Power consumption can go DOWN slightly for slow leaks

**See [Fixing Slow Leaks](#fixing-slow-leaks)**

### Fast Vacuum Leaks

* Turbo pump takes longer than XXXXX time to reach 90,000 rpm and current stays above 1.5A after speed levels off
* RGA filament turns off or RGA software stops scanning and won’t start.
* Turbo pump amperage rises above 1.5A and/or do

**See [Fixing Fast Leaks](#fixing-fast-leaks)**

### Configuration Issues

* Turbo pump does not reach speed, but current consumption is normal (xxxxx)
* Turbo pump does not respond to commands, but other ISMS commands work as expected.
* RGA Software Buttons are greyed out.

**See [Fixing ISMS Configuration Issues](#fixing-isms-configuration-issues)**

### PC Software Issues

* Serial Studio dashboard is jumbled or empty
* RGA Software panels are missing

**See [Fixing PC Software Issues](#fixing-pc-software-issues)**

### LED Light Meanings

 The ISMS has several LED lights labeled LED1 \- LED5 that indicate board status.

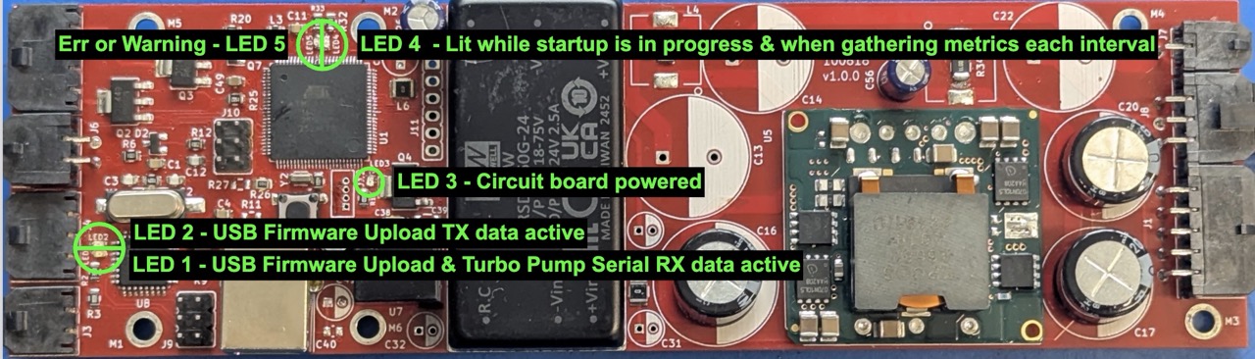
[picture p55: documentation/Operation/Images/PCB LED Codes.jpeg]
PCB LED Codes


* **LED 1 & LED 2:** Flashing quickly indicates that the USB-B port has data moving through it or a firmware update is in progress (this should not be lit or flash at all during normal operation)
* **LED 3:**  Indicates that the board has power on the 5v rail \- this LED should always be on while power supply “A” is plugged in. If out, check both power supplies for voltage. It could also indicate an issue with power

## Resolution

### Fixing Serial Connections

1. Add or remove a reverser/null modem to both RGA and ISMS serial cables and try again.
2. Make sure the ISMS serial is set to 9600 baud, 8 data bits, 1 stop bit, no parity, no flow control, and the correct COM port (or /dev/cu.xxxx on mac or /dev/ttyxxx on linux) is selected (you can verify this by unplugging one or the other and see which COM port remains available on the computer)
3. Make sure the RGA Serial cable is using the provided “Loopback Handshake” DB9 connector and that the RS232 to usb adapter supports the 22000xxxx bps baud rate of the RGA.
4. Make sure NO other programs that might try to connect to the serial ports are open such as the Arduino IDE, Multiple windows of the RGA software, Multiple Serial Studio connections, etc..
5. Power cycle ISMS with serial cables unplugged, then plug in both Serial to USB adapters after 10 seconds.

### Fixing Disconnections

1. Tighten all connections, make sure Subconn locking collars are in place.
2. Replace the USB to RS232 converters, null modems (if needed), power cables, etc..
3. Make sure NO other programs that might try to connect to the serial ports are open such as the Arduino IDE.
4. If these steps don’t work:
   1. Replace octopus subconn cable.
   2. Check internal terminal block connections
   3. Make sure that the ground of the ISMS is electrically isolated from the enclosure & water by checking for any metal on metal contact between parts of the sled, tubing, circuit board or vacuum system with the enclosure body.                               **\- see [Pressure Housing Opening and Sealing](#pressure-housing-opening-and-sealing)**

### Fixing Fluid Flow

1. Reverse the fluid pump - use the reverse fluid pump button in Serial Studio or send `FLUIDPUMP_RATE -100`
2. Check the sound of the pump when on deck, it should whine softly not grind \- any experience here dan xxxx?.
3. Flush fluid path with di water in both forward and reverse directions while running pump.
4. If no improvement, check for biofilms or buildup coating the membrane surface \- spray off membrane, and dry, or replace if needed \- **see [Membrane Replacement](#membrane-replacement).**

### Fixing Slow Leaks

1. Run just the roughing pump for several hours or overnight followed by the turbo pump again for several hours if heavy moisture buildup in the vacuum chamber is suspected.
2. Cap vacuum chamber at membrane inlet port and again attempt to pump down to reach a total pressure of less than xxxxx on the RGA.
   1. If this solves the issue, Replace membrane xxx and/or peek tubing between inlet and vacuum chamber.
3. Check that the cooling pad on the turbopump is making good contact with the ISMS endcap xxxxx \- this doesn't exist yet, but I think it is a good idea\!

### Fixing Fast Leaks

1. Power down RGA Filament and Turbo pump to avoid damage.
2. Run just the roughing pump for a while and retry powering the turbo pump to see if the moisture/air load goes down and the turbo can reach speed without steady high currents.
3. Inspect membrane and o-rings on inlet and consider replacing.
4. Check fittings that might have come loose.

### Fixing ISMS Configuration Issues

1. The turbo pump controller may have target rpm misconfigured or has a power limit set
   1. Send *TURBO\_RESET* to fix these problems & restore default speed setpoint, 100% power limit and other parameters.
   2. For a range of other commands to troubleshoot & configure the Turbo pump, **see [TC 80 Electronic Control Unit Manual](<./Component Manuals/Turbo Pump Control Unit Manual Pfeiffer-TC-80_Operating-Instructions.pdf>)**, Section 6
      1. Turbo pump commands can be sent in this format: *TURBO\_CMD 000 12345* Where 000 is the 3-digit parameter number and 12345 is the value to set it to as an integer, decimal, 1 for True, 0 for False, or the function number in the table.
      2. Parameters can be read from the turbo by sending a command in this format:
         *TURBO\_QUERY 000*  \-  where 000 is the 3-digit parameter number to read.
      3. If TURBO\_CMD and TURBO QUERY are insufficient the TURBO\_RAW command can be used to send raw ascii to the turbo pump over RS482, note you must encode this command by hand following the turbo pump protocol.

### Fixing PC Software Issues

1. For grayed out buttons on the RGA software, make sure the filament is on & serial

2. For issues with Serial Studio, check that the connection settings are set to Serial mode, the baud rates correct (see [Fixing Serial Connections](#fixing-serial-connections)) and the correct layout preset file is selected: [ISMS V3 Serial Studio Dashboard](#TODO), and

3.

### Fixing Power Supply Issues

1. Check that both power supply “A” and power supply “B” are connected and on at ≥ 24v and the ground wires from BOTH power supplies are connected to the tether per the topside wiring diagram, but do not otherwise make “loops” where the same ground path is connected in two places with a gap in-between or a long distance of wire (power or signal) are coiled up.
2. Check the power supply for voltage sag & noise while starting various sub components using a multimeter or oscilloscope.
3. Ensure the vacuum chamber has pumped out sufficiently (rough out for minimum 30mins to 1 hour from storage) before starting the RGA filament for measurement, otherwise you may get overpressure or undervoltage warnings in the RGA software.
4. Check that LED3 is on solidly while the instrument is powered (visible on the main board after sliding out the sled \- see [Pressure Housing Opening and Sealing](#pressure-housing-opening-and-sealing)).
5. Confirm that the voltages on the board match expectations by probing the connector labeled “J1” or “Unused power taps” in [ISMS PCB Pinouts Annotated.png](<../Fabrication/Wiring/Build Images/Internal/ISMS PCB Pinouts Annotated.png>) \- voltage mismatch here indicates a faulty DC-DC converter that should be replaced or higher than expected loads.

### Pressure Housing Opening and Sealing

1. Tip for opening the housing:
   1. Use several plastic cards like gift cards to work around the enclosure face seal of the endcap with penetrations. Wedge cards into the gap to keep creating wider stacks of cards and work around the edge similar to removing a bike tire. \- DO NOT use metal tools.
   2. If this is too difficult, use pressure to help: Unscrew the pressure relief valve and pressurize the enclosure up to 1-2 PSI \- NO HIGHER, otherwise the enclosure will turn into a cannon. The Blue Robotics vacuum plug adapter threads into the pressure relief valve hole perfectly and can be used with a suitable face o-ring to pressurize the enclosure and make it easier to pull apart.
   3. There is rarely a need to open the rear flat end cap and it should be left as is.
   4. Slide out the end cap with penetrations and internal sled as one unit, being careful not to let the inner sled metal rails past the last cross section plastic disk scratch the inner surfaces of the housing.
2. Re-sealing
   1. Wipe away debris and old grease with a lint-free cloth
   2. Use molykote 44 medium o-ring grease to lightly grease all o-rings
   3. Slide chassis assembly along with main endcap into tube, making sure the rails don’t scratch the inner surfaces of the housing.
      1. Add large desiccant packs to absorb the water vapor that will be ejected from the vacuum pumps into the housing as you go where they will fit.
   4. Remove the vent plug from the end cap:
      - Vent Plug
   5. Turn the whole ISMS enclosure vertically onto the flat opposite end cap.
   6. Press down firmly, making sure the face o-ring stays centered in its groove as it goes \- extra grease on that side may help keep it in the groove.
   7. Expand the black housing clamp slightly and install over the flange clamp protrusions, then install the hose clamp over that and tighten
      - Clamp Ring Sled Install
      - Housing Closed

### Membrane Replacement

See the [main sled fabrication documentation](<../Fabrication/Main Sled/README.md#assembling-inlet>) assembling inlet section.
- When cutting membranes use a backing material like teflon board and cut 16mm discs using a cutting press, arbor press, or hammer along with a 16mm cutting circle edge punch \- an example is in the parts list tool sheet.

### Wiring Details

The recommended topside wiring is shown below:
> For more details see the topside section of the [Wiring Guide](../Fabrication/Wiring/README.md)

ISMS Recommended Topside Wiring

The full wiring of the entire ISMS instrument setup can be seen [here](<../Documentation Diagram Source Materials/Full Wiring Diagram Attempts/plantuml.png>):

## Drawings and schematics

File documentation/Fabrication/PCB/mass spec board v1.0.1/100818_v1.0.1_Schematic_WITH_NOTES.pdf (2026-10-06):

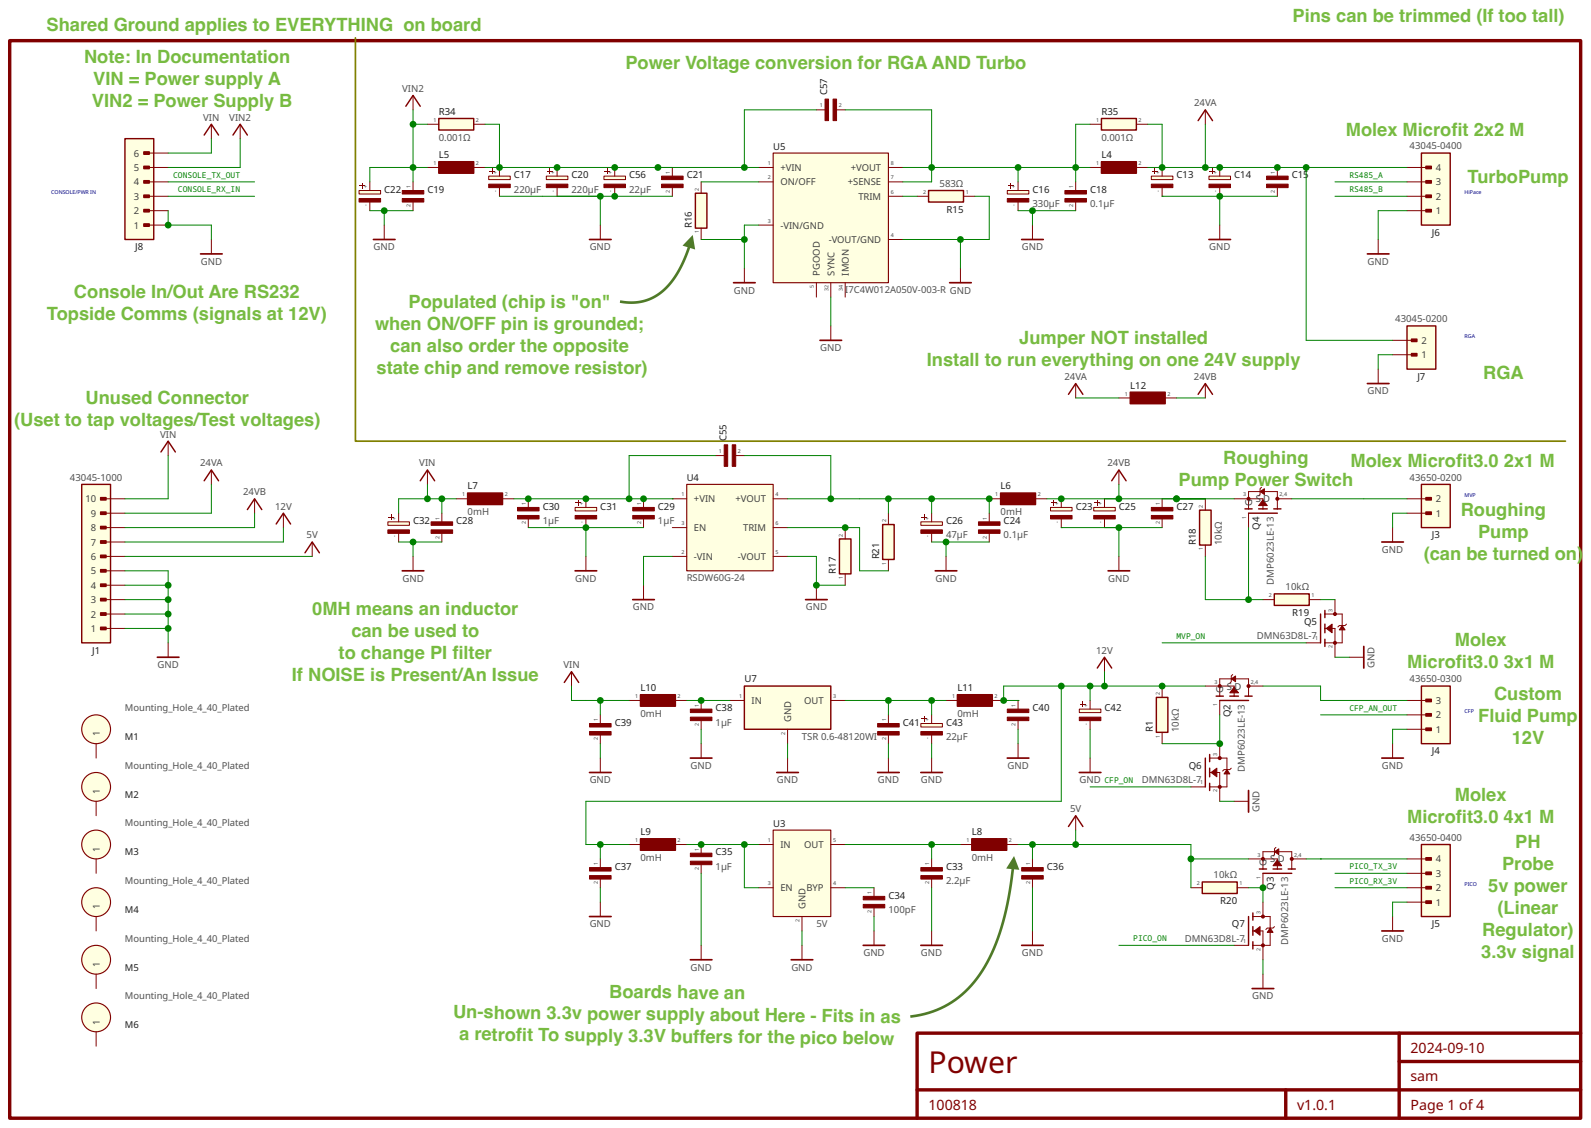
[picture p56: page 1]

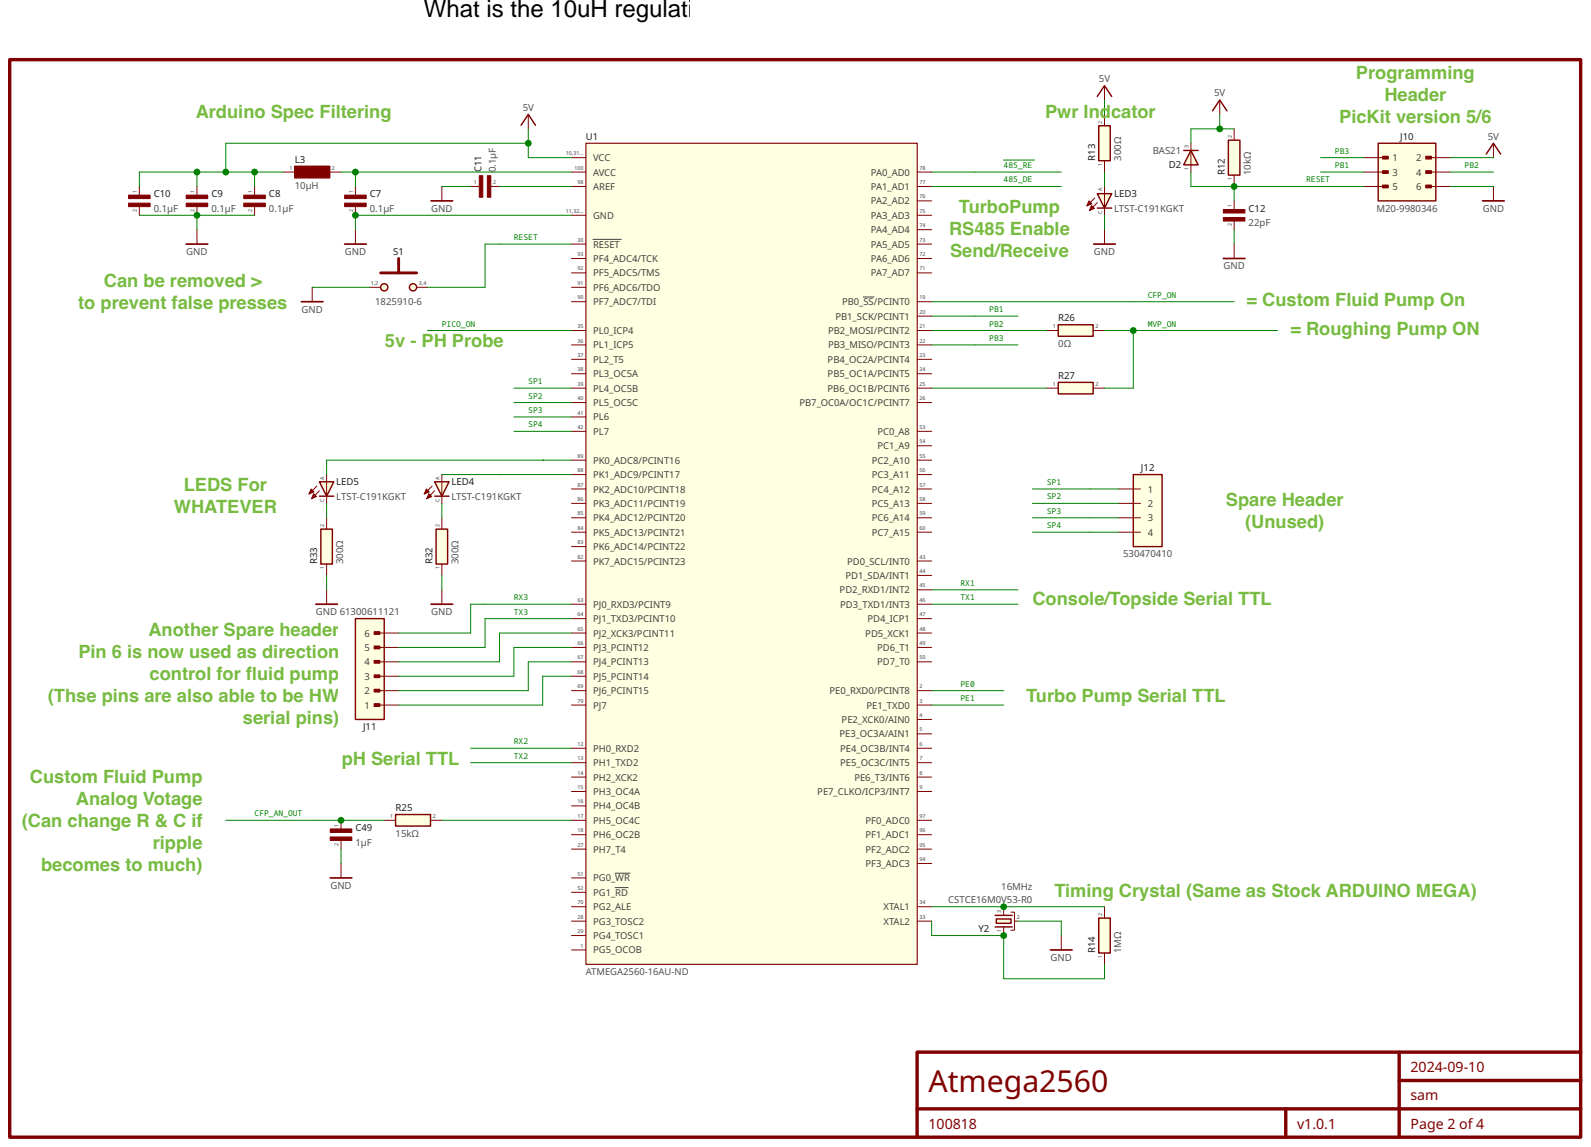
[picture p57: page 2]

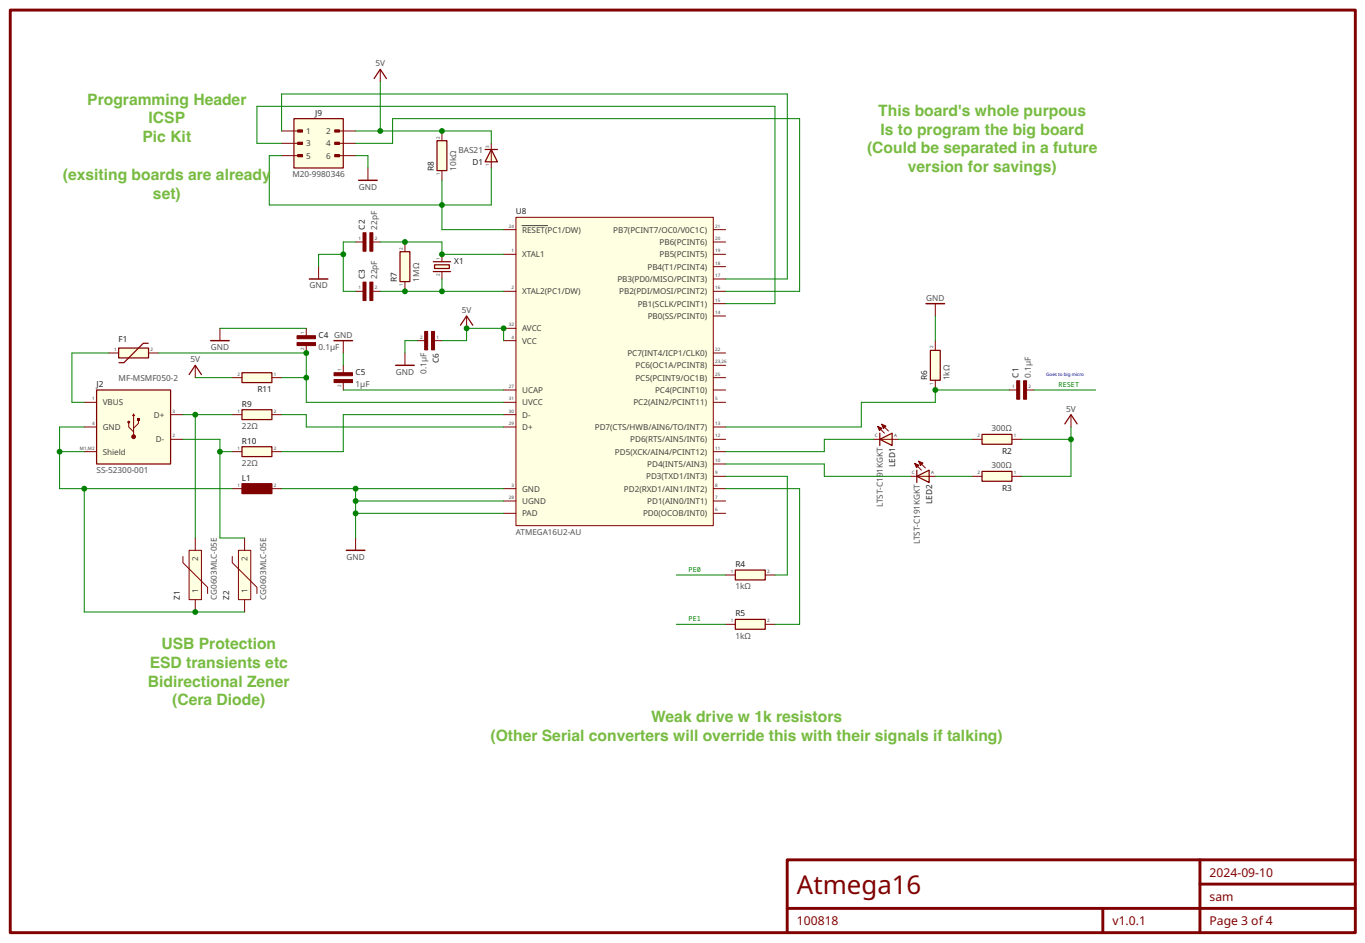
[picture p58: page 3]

Goes to big micro
RESET

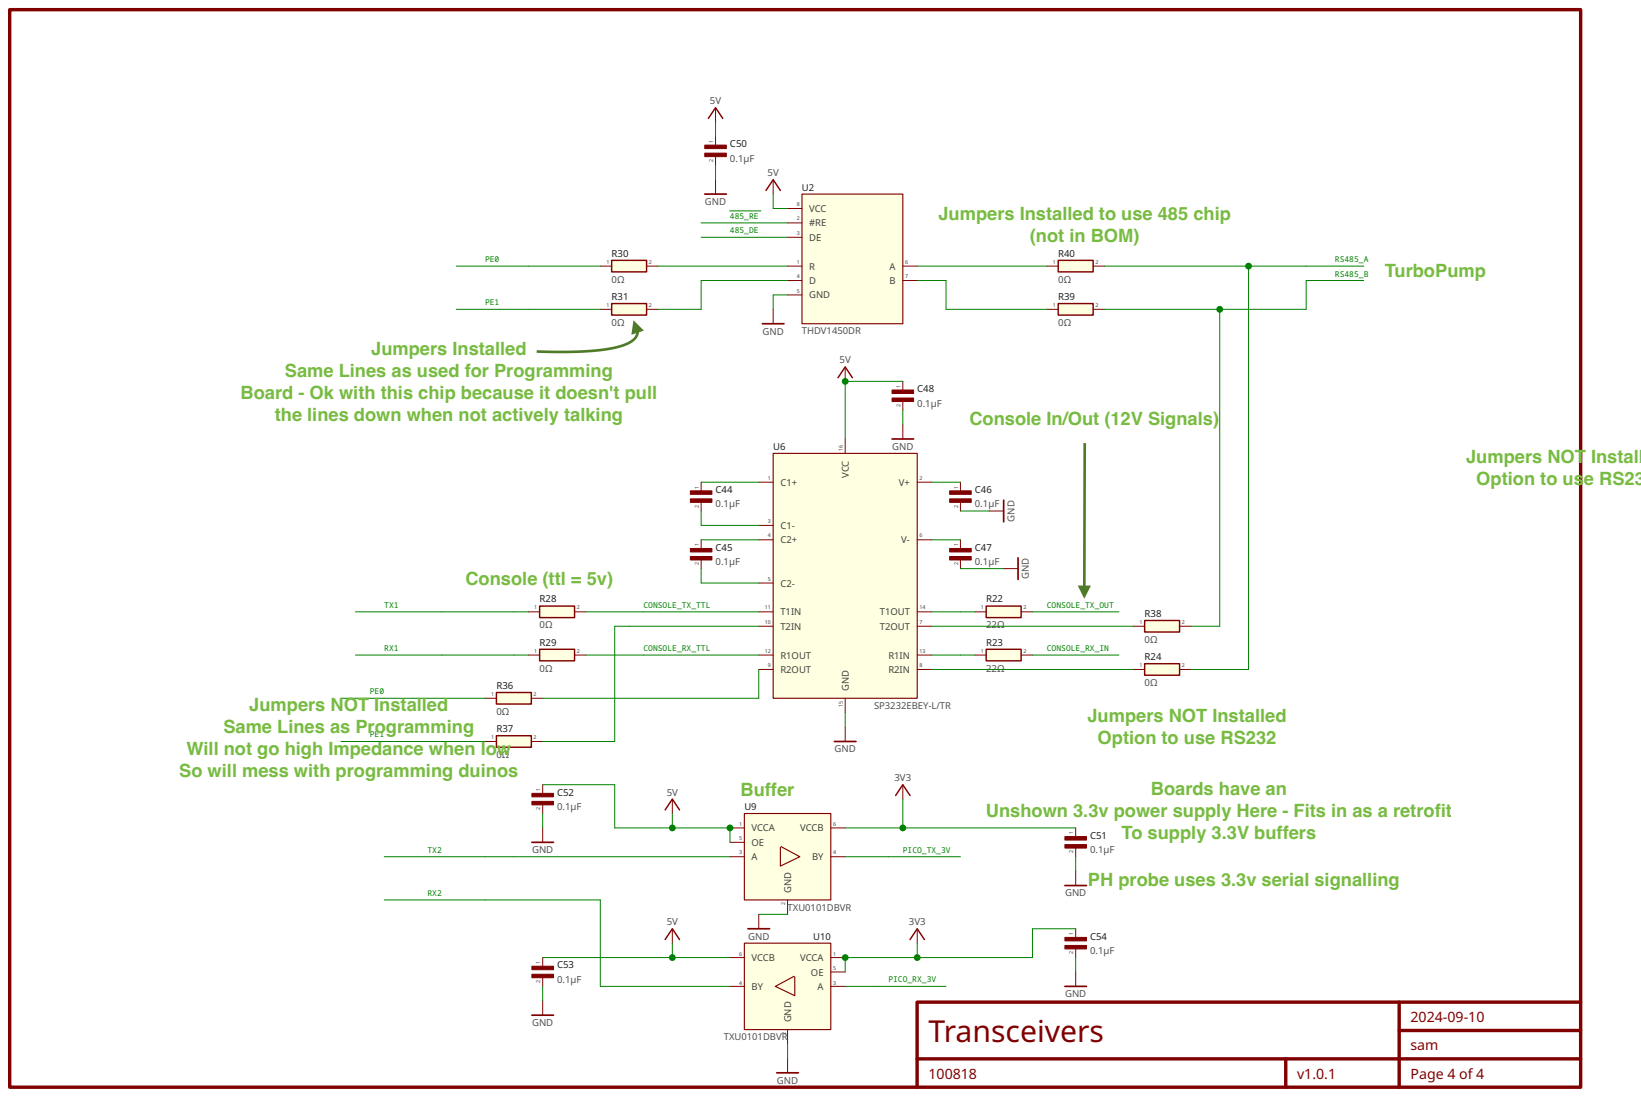
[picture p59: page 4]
GND 2; VCC 16; GND 15

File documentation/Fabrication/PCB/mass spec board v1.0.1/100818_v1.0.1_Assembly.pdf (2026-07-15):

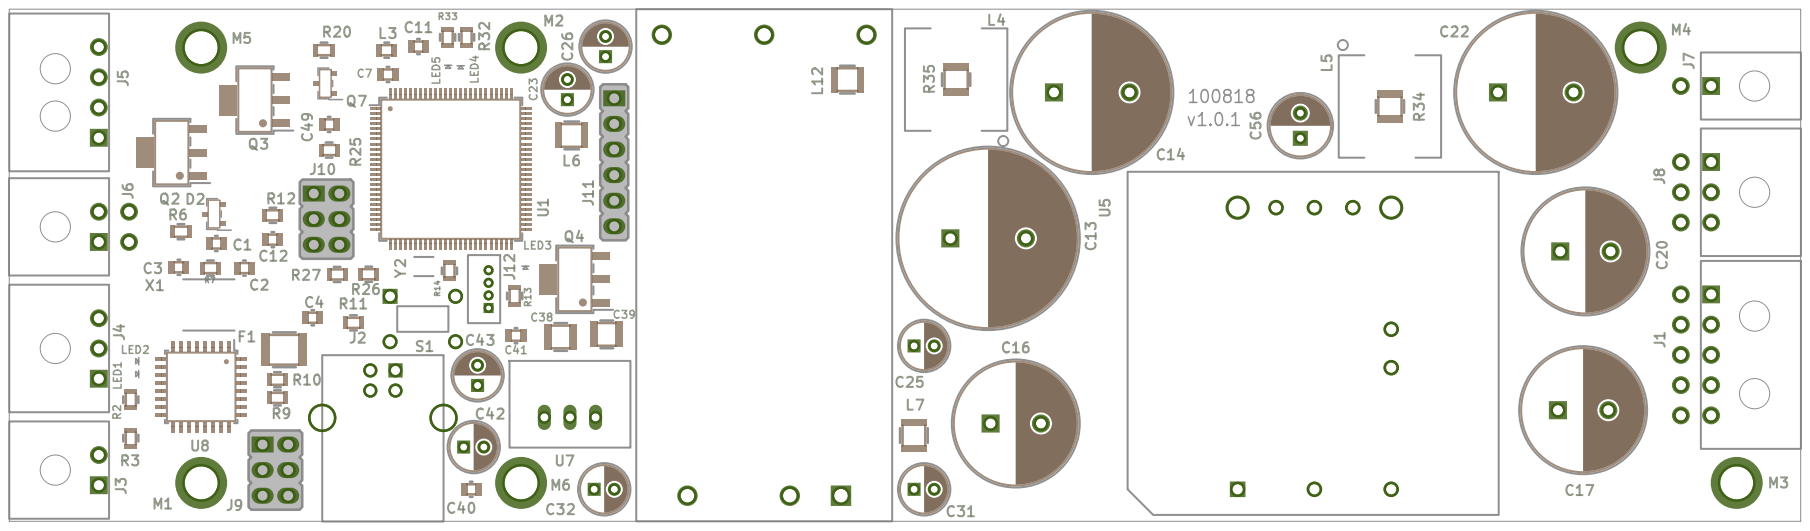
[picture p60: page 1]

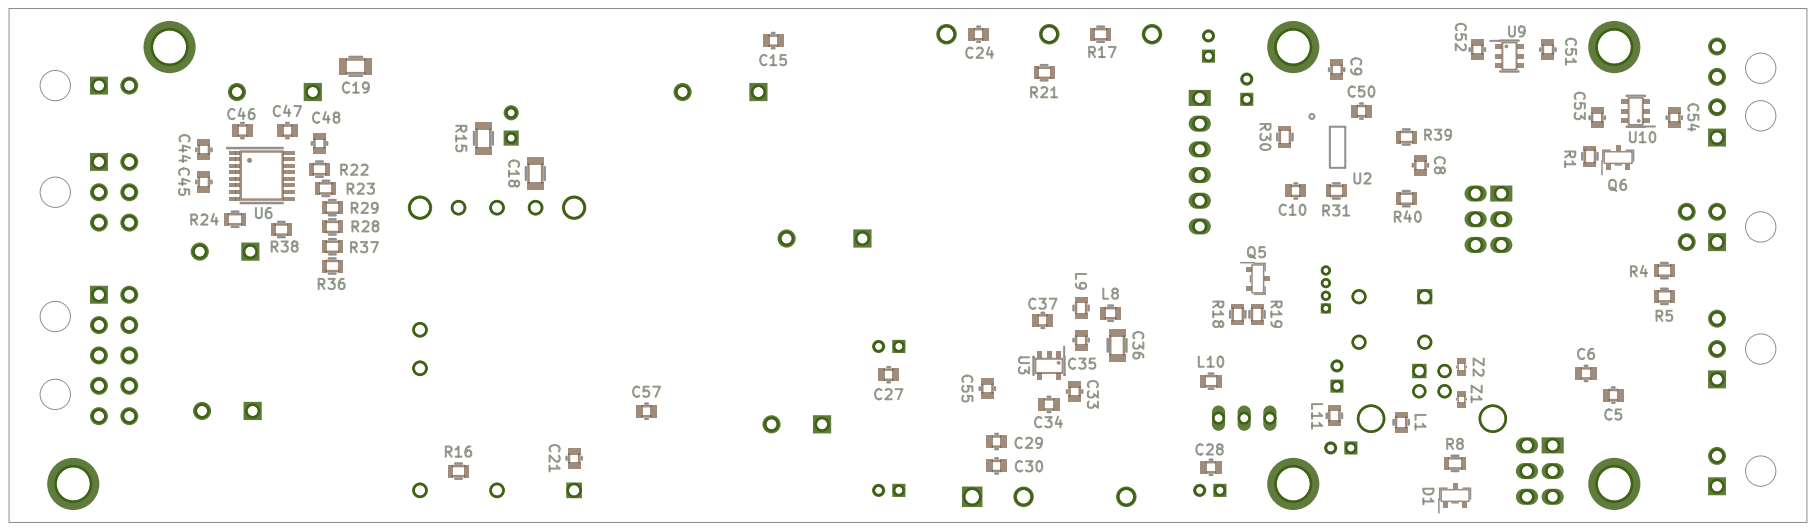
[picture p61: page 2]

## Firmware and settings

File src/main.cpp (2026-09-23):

// Entry point and main loop for the ATMEL2560 based ISMS controller.
//
// This is the V3 redesign of the ISMSs with dedicated PCB (Year 2025/26).
//
// Brings the instrument up in setup() -- watchdog, operator serial port, saved
// settings, switched power rails, turbo pump, fluid pump, and the optional
// automatic startup sequence -- then spends loop() broadcasting the periodic
// stats telegram that operators and the topside software read. Also provides
// nonBlockDelay(), the cooperative delay that every waiting routine in this
// firmware uses so that serial commands keep being answered and the watchdog
// keeps being petted no matter how long an operation takes.
//
// To compile this project, use Visual Studio Code IDE and install the
// PlatformIO Extension. Use PlatformIO buttons in the bottom toolbar to
// compile, and upload. Uploads must be done with the USB b port on the circuit
// board, however serial data comes from the RS232 output (the serial of the
// USB B port is joined to the TURBO Pump RS485 Serial).

#include "includes.h"
#include "modernCommands.h"

bool autostarted = false; // Becomes true once autostart has happened, so we don't do it again
// Lowest free RAM seen since boot, so the stats telegram can warn about a slow
// leak or a deep call path even after the memory has been reclaimed.
int minFreeRam = getTotalRam();

// Services the background work that must keep happening no matter what else is
// running.
//
// Pets the watchdog, lets the turbo pump's RS485 driver turn the transceiver
// around and drain its buffers, and tracks the low-water mark of free RAM.
// Called from the innermost loop of nonBlockDelay(), so it runs every few
// microseconds while any part of the firmware is waiting.
void taskTick()
{
  resetWDT();
  turboSerialRS485.task();
  int freeRam = getAvailableRAM();
  if (freeRam < minFreeRam)
    minFreeRam = freeRam;
}

// How many levels of nonBlockDelay() nesting are still allowed to execute
// operator commands.
//
// Commands recived from the user via serial are dispatched from inside nonBlockDelay(),
// and if those commands also use nonBlockDelay(), the commands can stack recursively and
// use up all memory (stacks another LazySerial line buffer, Context and handler
// frame -- on the order of 200 bytes -- onto an SRAM stack that has no overflow
// detection).
//
// Two levels is the smallest limit that keeps the behaviour the instrument
// depends on: loop() waits (level 1) and dispatches STARTUP, and STARTUP's own
// 60 second rough-out wait (level 2) still dispatches the BEAT that aborts it.
// Three is used instead, so that a command dispatched from inside a pause that
// is itself a command -- HELP's 4 second reading pause being the one an
// operator hits by accident -- can still be aborted. The cost of the extra
// level is bounded: worst case three nested LazySerial line buffers and
// handler frames, on the order of 600 bytes against the ~3.8 KB free.
//
// Deeper waits only tick background work; bytes stay queued in the UART receive
// buffer and are executed once the outer wait resumes, so commands are answered
// late rather than nested. Input arriving faster than that buffer holds it (64
// bytes on the ATmega2560) while a deep wait runs is still dropped by the UART.
#define NONBLOCK_DELAY_MAX_DISPATCH_DEPTH 3

// How long after the most recent byte nonBlockDelay() keeps waiting when the
// operator is part way through typing a command. Also the hard cap on the total
// extension, so the wait can never run more than this past the requested
// interval no matter how long the operator keeps typing.
#define NONBLOCK_DELAY_TYPING_GRACE_MS 3000

// Current nonBlockDelay() nesting depth; 0 when no wait is in progress.
static uint8_t nonBlockDelayDepth = 0;

// Scope guard for that depth: constructing it enters one level of
// nonBlockDelay() and destroying it leaves, so the count stays correct however
// the function returns.
struct NonBlockDelayLevel
{
  NonBlockDelayLevel() { ++nonBlockDelayDepth; }
  ~NonBlockDelayLevel() { --nonBlockDelayDepth; }
  // True while this level is shallow enough to run operator commands.
  bool mayDispatch() const { return nonBlockDelayDepth <= NONBLOCK_DELAY_MAX_DISPATCH_DEPTH; }
};

// Waits roughly `ms` milliseconds without stalling the firmware's background
// work, and reports whether an operator command arrived while waiting.
//
// Spins on micros() -- which handles counter rollover -- calling taskTick() for
// the whole interval, so the watchdog is still petted and the turbo pump's
// RS485 line is still serviced inside even a 60 second wait. The command line
// is polled too, but only while the wait is within
// NONBLOCK_DELAY_MAX_DISPATCH_DEPTH levels of nesting, which is what keeps
// command execution from stacking up on itself.
//
// A poll that reads bytes without completing a line means a command is being
// typed, so the wait is stretched to NONBLOCK_DELAY_TYPING_GRACE_MS past that
// byte to let the operator finish -- re-armed by each further byte, never
// shortening the requested interval, and never running more than one grace
// period past it. Input that arrives complete (the topside GUI's packets, or a
// line the poll executes on the spot) leaves nothing half typed and so extends
// nothing.
//
// `ms` is clamped to NONBLOCK_DELAY_MAX_MS, above which the conversion to
// microseconds would wrap and produce a wait far shorter than asked for. The
// commands that set a wait already reject anything longer, so this only fires
// on a value that reached us some other way -- a corrupted EEPROM setting, or
// a future caller that computes its own interval.
//
// Returns true if a command was executed during the wait. Callers use this to
// abandon a long sequence the operator has just overridden; waits too deeply
// nested to dispatch execute nothing and so always report false.
bool nonBlockDelay(unsigned long ms)
{
  NonBlockDelayLevel level;
  const bool mayDispatchUserCommand = level.mayDispatch();

  if (ms > NONBLOCK_DELAY_MAX_MS)
    ms = NONBLOCK_DELAY_MAX_MS;

  const unsigned long start = micros();
  const unsigned long interval = ms * 1000UL;
  const unsigned long graceCap = interval + NONBLOCK_DELAY_TYPING_GRACE_MS * 1000UL;
  unsigned long window = interval; // the wait itself, grown only by half typed input
  bool commandRecieved = false;

  // Non-blocking delay, handles rollover
  while (micros() - start < window)
  {
    taskTick();
    if (!mayDispatchUserCommand)
      continue;

    // lazy.loop() drains everything COMMS has queued, so bytes that were
    // waiting but did not complete a command are a half typed line sitting in
    // LazySerial's buffer -- the only case worth waiting longer for.
    const bool hadBytes = (COMMS.available() != 0);
    const bool dispatched = lazy.loop();
    commandRecieved = commandRecieved || dispatched;

    if (hadBytes && !dispatched)
    {
      unsigned long extended = (micros() - start) + NONBLOCK_DELAY_TYPING_GRACE_MS * 1000UL;
      if (extended > graceCap)
        extended = graceCap; // one grace period past the requested interval, no more
      if (extended > window)
        window = extended; // only ever wait longer, never cut the caller's interval short
    }
  }

  // return if a bool indicating if a user command was processed.
  return commandRecieved;
}

// Prints the separator that follows one value in the stats telegram, flagging
// the value first if it looks wrong.
//
// When INCLUDE_OUT_OF_NORMAL_RANGE_MARKS is defined, a "(!)" marker is emitted
// before the comma if `gotValidResponse` is false or if `value` falls outside
// the inclusive range [`minOk`, `maxOk`], which makes a bad reading easy to
// pick out of a long log. The bounds are inclusive because several of the
// values checked sit exactly on one of them in normal operation -- the fluid
// pump at 100% after STARTUP, the turbo pump at its nominal speed -- and
// flagging those would make the marker useless. The trailing comma is always
// printed, so the telegram's field layout does not change when the marks are
// compiled out.
void log_value_postfix(float value, float minOk, float maxOk, bool gotValidResponse)
{
#ifdef INCLUDE_OUT_OF_NORMAL_RANGE_MARKS
  if (!gotValidResponse || value < minOk || value > maxOk)
  {
    COMMS.print("(!)");
  }
#endif
  COMMS.print(",");
}

// Arduino Standard function run at power-on or after a reset. Initializes the instrument once.
//
// Starts the watchdog, brings up the operator serial port and waits 5 seconds
// so the first messages are not lost to a link that is still settling, reports
// why the board last reset, registers the serial commands, then loads the
// saved settings and applies the saved log level. Every switched rail and both
// pumps are explicitly driven off, so a reboot mid-deployment does not leave
// the instrument in a half-running state. Finally, runs the full startup
// sequence if autostart is enabled and BEAT has not already cancelled it, and
// warns the operator if the periodic stats telegram is switched off.
void setup()
{
  // LED1 on to indicate setup done
  LED4_PWR.turnOn();
  wdtStart();
  resetWDT();
  // wdtStop(); // uncomment to disable watch dog timer
  COMMS.begin(COMMS_BAUDRATE);
  COMMS.println("| Wait for startup...");

  delay(5000); // 5s delay to allow serial connection to establish before we start sending data, which can cause the first messages to be lost
  resetWDT();

  // Print startup messages
  COMMS.println("| ISMS Initializing... [ Firmware Version " FIRMWARE_VERSION " ]");
  wdtPrintStatus(COMMS); // Print the startup status from the watchdog to the COMMS serial for reference
  COMMS.print("| Free RAM baseline: ");
  COMMS.println(getAvailableRAM());

  // Setup commands, logging and load saved settings
  // LazySerial::CallbackFunction all_comms_commands[COUNT_OF(basic_comms_commands) + COUNT_OF(debug_comms_commands)];
  // concatArrays(basic_comms_commands, debug_comms_commands, all_comms_commands); // join the basic and debug commands into an array with all commands for lazy serial
  lazy.set_commands(all_comms_commands);
  lazy.set_help_callback(lazy_help_callback);
  LOG_ATTACH_SERIAL(COMMS);
  LOG_SET_DELIMITER("");
  LOG_SET_LEVEL(DEBUG_LOG_LEVEL_OFF);
  load_settings();
  LOG_SET_LEVEL((DebugLogLevel)constrain((uint8_t)saved_settings.log_level, (uint8_t)DEBUG_LOG_LEVEL_OFF, (uint8_t)DEBUG_LOG_LEVEL_HIGH)); // Log levels below INFO/DEBUG_OFF are NOT used, because they may hide expected log messages.

  // Clamp the two timing settings to the range their commands enforce. The
  // commands that write them already reject anything out of range, but
  // load_settings() validates only struct_initialized and struct_version -- a
  // single flipped EEPROM bit in either field passes both checks and would
  // otherwise be acted on unbounded.
  saved_settings.autostart_delay = constrain(saved_settings.autostart_delay, 0UL, NONBLOCK_DELAY_MAX_MS);
  saved_settings.stats_log_interval = constrain(saved_settings.stats_log_interval, STATS_INTERVAL_MIN_MS, NONBLOCK_DELAY_MAX_MS);

  // Setup Pins and ensure everything is off to start
  LED4_PWR.begin(HIGH);     // LED 1: Status Indicator light - stays on until setup finishes
  LED5_PWR.begin(LOW);      // LED 2: Warning/error Indicator light
  ACCESSORY_PWR.begin(LOW); // Accessory/Ph probe power pin
  ROUGHING_PWR.begin(LOW);  // Roughing vacuum pump power pin

  // Begin turbo pump serial interface and turn the pump off to start (in case of reboot)
  turboTC80.begin();
  turboTC80.sendCommand(PfeifferVacProtocol::ControlCommand::MotorPump, PfeifferVacProtocol::BooleanOld(false));

  // Initialize fluid pump control and ensure it's off to start
  fluidPump.init();
  fluidPump.setSpeed(0); // Ensure fluid pump is off

  // Turn off LED1 on to indicate setup done
  LED4_PWR.turnOff();

  // auto initilize system
  if (saved_settings.autostart_on && !autostarted && !beatActive)
  {
    autostarted = true;
    nonBlockDelay(saved_settings.autostart_delay);
    // Run the startup sequence automatically (user can intervene by sending the BEAT command)
    run_startup_sequence(false);
  }

  // Warn operator if stats logging is disabled.
  if (!saved_settings.stats_loging_enabled)
  {
    LOG_WARN(F("!WARN: Stats Logging disabled, send STATS_INTERVAL <ms> to set stats logging interval.\n"));
  }
}

// Prints the value fields of one stats telegram, accumulating warnings about
// what it read into `warnings`.
//
// Prints the fluid pump rate, then queries the turbo pump for its speed
// setpoint, actual speed, drive current, and rotor, electronics and pump
// bottom temperatures, then the state of the switched power rails -- each
// value followed by log_value_postfix(), so readings outside their normal band
// stand out. Along the way it accumulates plain-language warnings for missing
// or malformed pump replies and for readings that indicate trouble (a low
// turbo RPM risks burning out the RGA filament).
//
// Yields through nonBlockDelay() between queries so commands are still
// answered and the watchdog still petted while the telegram is assembled.
//
// Returns true if the whole telegram was printed, false if one of those yields
// executed an operator command and the remaining fields were abandoned -- on
// the assumption that the operator's request matters more than a complete line
// of stats. Every yield sits immediately after a field's trailing comma, so a
// false return always leaves the partial record comma-terminated and the
// caller's truncation marker appends cleanly. Emits no newline in either case:
// log_stats() owns the end of the line.
static bool log_stats_values(String &warnings)
{
  bool responseIsValid = true;

  LOG_INFO("Fluidpump_Rate:", fluidPump.getSpeed(), "%");
  // Bounds admit the pump's full commanded range: 0 is stopped and negative is
  // reverse, both legitimate states. A low or reversed speed that actually
  // matters is warned about explicitly just below.
  log_value_postfix((float)fluidPump.getSpeed(), -100, 100, true);
  if (FLUIDPUMP_PWR.getState() == 1)
  {
    if (fluidPump.getSpeed() < 0)
    {
      warnings += F("Fluid pump running backwards, use FLUIDPUMP_RATE 100 to go full speed forwards, ");
    }
    if (abs(fluidPump.getSpeed()) < 20)
    {
      warnings += String(F("Fluid pump set to a low speed (")) + String(fluidPump.getSpeed()) + F("%) set FLUIDPUMP_RATE xxx higher for consistant flow, ");
    }
  }
  if (nonBlockDelay(5))
    return false; // Yield to allow command checks to run and reset WDT, while ensuring stats logging doesn't cause long pauses

  LOG_DEBUG("\n");
  unsigned long turboRpmTarget = turboTC80.queryUInteger(PfeifferVacProtocol::StatusRequest::SetRotSpdRpm, responseIsValid, false);
  if (!responseIsValid)
    warnings += F("Turbo_RPM_Setpoint wrong or missing response, ");
  LOG_INFO("Turbo_RPM_Setpoint:", turboRpmTarget);
  log_value_postfix((float)turboRpmTarget, 50000, 95000, responseIsValid);
  if (nonBlockDelay(5))
    return false; // Yield to allow command checks to run and reset WDT, while ensuring stats logging doesn't cause long pauses

  responseIsValid = true;
  LOG_DEBUG("\n");
  unsigned long turboRpm = turboTC80.queryUInteger(PfeifferVacProtocol::StatusRequest::ActualSpdRpm, responseIsValid, false);
  if (!responseIsValid)
    warnings += F("Turbo_RPM wrong or missing response, ");
  else if (turboRpm > 1 && turboRpm < TC80_TURBO_LOW_SPEED_WARNING_RPM)
    warnings += F("Low Turbopump RPM - ensure RGA filament is OFF to avoid burnout, ");
  LOG_INFO("Turbo_RPM:", turboRpm);
  log_value_postfix((float)turboRpm, 50000, 95000, responseIsValid);
  if (nonBlockDelay(5))
    return false; // Yield to allow command checks to run and reset WDT, while ensuring stats logging doesn't cause long pauses

  responseIsValid = true;
  LOG_DEBUG("\n");
  float turboCurrent = turboTC80.queryUReal(PfeifferVacProtocol::StatusRequest::DrvCurrent, responseIsValid, false);
  if (!responseIsValid)
    warnings += F("Turbo_Current wrong or missing response, ");
  LOG_INFO("Turbo_Current:", turboCurrent, "A");
  log_value_postfix(turboCurrent, 0.2, 5.2, responseIsValid);
  if (nonBlockDelay(5))
    return false; // Yield to allow command checks to run and reset WDT, while ensuring stats logging doesn't cause long pauses

  responseIsValid = true;
  LOG_DEBUG("\n");
  unsigned long turboRotorTemp = turboTC80.queryUInteger(PfeifferVacProtocol::StatusRequest::TempRotor, responseIsValid, false);
  if (!responseIsValid)
    warnings += F("Turbo_Rotor_Temp wrong or missing response, ");
  LOG_INFO("Turbo_Rotor_Temp:", turboRotorTemp, "C");
  log_value_postfix((float)turboRotorTemp, 0, 60, responseIsValid);
  if (nonBlockDelay(5))
    return false; // Yield to allow command checks to run and reset WDT, while ensuring stats logging doesn't cause long pauses

  responseIsValid = true;
  LOG_DEBUG("\n");
  unsigned long turboElecTemp = turboTC80.queryUInteger(PfeifferVacProtocol::StatusRequest::TempElec, responseIsValid, false);
  if (!responseIsValid)
    warnings += F("Turbo_Elec_Temp wrong or missing response, ");
  LOG_INFO("Turbo_Elec_Temp:", turboElecTemp, "C");
  log_value_postfix((float)turboElecTemp, 0, 70, responseIsValid);
  if (nonBlockDelay(5))
    return false; // Yield to allow command checks to run and reset WDT, while ensuring stats logging doesn't cause long pauses

  responseIsValid = true;
  LOG_DEBUG("\n");
  unsigned long turboBottomTemp = turboTC80.queryUInteger(PfeifferVacProtocol::StatusRequest::TempPmpBot, responseIsValid, false);
  if (!responseIsValid)
    warnings += F("Turbo_Bottom_Temp wrong or missing response, ");
  LOG_INFO("Turbo_Bottom_Temp:", turboBottomTemp, "C");
  log_value_postfix((float)turboBottomTemp, 0, 60, responseIsValid);
  if (nonBlockDelay(5))
    return false; // Yield to allow command checks to run and reset WDT, while ensuring stats logging doesn't cause long pauses

  responseIsValid = true;
  LOG_DEBUG("\n");

  uint16_t turboPowerLimit = turboTC80.queryUShortInt(PfeifferVacProtocol::ReferenceValueInput::PwrSVal, responseIsValid, false);
  if (!responseIsValid)
  {
    warnings += F("Turbo_Power_Limit wrong or missing response, ");
  }
  else if (turboPowerLimit < 100)
  {
    warnings += String(F("Turbo Power Limit set to ")) + String(turboPowerLimit) + F("%, ");
  }
  if (nonBlockDelay(5))
    return false; // Yield to allow command checks to run and reset WDT, while ensuring stats logging doesn't cause long pauses

  LOG_INFO("Roughing_on:", ROUGHING_PWR.getState(), ",");
  LOG_INFO("Fluidpump_on:", FLUIDPUMP_PWR.getState(), ",");
  LOG_INFO(ACCESSORY_NAME "_on:", ACCESSORY_PWR.getState());

  return true;
}
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
void loop()
{
  // always wait at least 1 ms between stats logs to allow lazy serial commands to be processed and WDT resets to happen, while ensuring stats logging doesn't cause long pauses
  nonBlockDelay(1); // Wait 1 ms between checks to see if it's time to log stats again, while still allowing lazy serial commands to be processed and WDT resets to happen

  // Check if it's time to log stats again, based on the user configured interval in saved settings. If not, return early.
  if (millis() - lastStatsLogTime < saved_settings.stats_log_interval)
  {
    // Turn off LED1 on to indicate the ISMS is between logging events
    LED4_PWR.turnOff();
    // Return to avoid logging
    return;
  }

  // Turn on LED1 on to indicate the ISMS has started a stats log event.
  LED4_PWR.turnOn();
  if (saved_settings.stats_loging_enabled)
  {
    log_stats();
  }
  else
  {
    nonBlockDelay(100); // delay to give the status LED time to visibly flash.
  }

  // Stamp the time the telegram *finished*, not the time it started. A
  // telegram can easily outrun its own interval -- the error queries above
  // block for up to 5 seconds each -- and timing from the start would then
  // make the next one due the moment this one ends, with no gap for anything
  // else.
  lastStatsLogTime = millis();

  // Turn off LED1 after the ISMS has done one stats log
  LED4_PWR.turnOff();
}

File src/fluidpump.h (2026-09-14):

// Fluid pump control for the ISMS sample pump.
//
// Drives a Micropump EagleDrive gear pump through three signals -- a power
// relay (a powerPin), an analog 0-5 V speed reference, and a direction line --
// and presents them as one signed percentage, so the FLUIDPUMP and
// FLUIDPUMP_RATE serial commands and the automatic startup sequence can set
// flow in a single call. Header-only; the single global instance lives in
// includes.h.
//
// Pump manual:
// https://micropump-nova.s3.us-west-2.amazonaws.com/687/Micropump-EagleDrive-v1_5-Install-Operation-Warranty-Manual.pdf

#ifndef FLUIDPUMP_H
#define FLUIDPUMP_H

// Milliseconds the speed line must be held near full scale after power-on to
// put the pump into PWM control mode. Applies only to the PWM control path,
// which loopHandler() currently leaves disabled.
#define FLUIDPUMP_PWM_STARTUP_DURRATION 2500

// Value setSpeed() returns when init() has not been called yet. Deliberately
// outside the valid -100 to 100 range so callers can tell it apart from a real
// speed.
#define FLUID_PUMP_UNINITIALIZED -999

#include <Arduino.h>

// Controls the fluid pump's power, speed, and direction.
//
// The pump is driven from the analog speed reference, which needs no enable
// handshake: the power relay is closed and a 0-5 V level sets the flow rate.
// The manufacturer's alternative PWM control mode instead requires the speed
// line to be held high for the first FLUIDPUMP_PWM_STARTUP_DURRATION
// milliseconds of every power-on, and that sequencing is kept -- commented
// out -- in loopHandler() in case the wiring moves back to PWM.
class FluidPump
{
public:
    // Binds the pump to the power relay `pumpPower` and to the `pwmPin` speed
    // output and `reverseDirectionPin` direction output.
    //
    // Records the pins and starts stopped; no hardware is touched until init()
    // runs, so this is safe to use for a global instance.
    FluidPump(powerPin *pumpPower, uint8_t pwmPin, uint8_t reverseDirectionPin)
        : pumpPower(pumpPower), pwmPin(pwmPin), reverseDirectionPin(reverseDirectionPin), initialized(false), pumpEnableComplete(false), timeWhenEnabled(0), currentSpeedPercent(0) {}

    // Prepares the pump's pins and leaves the pump stopped.
    //
    // Configures the speed and direction pins as outputs, forces the speed to
    // 0 (which also opens the power relay, so a reboot mid-run does not leave
    // the pump spinning), and marks the pump usable by setSpeed(). Call once
    // from setup(), before any other method.
    void init()
    {
        pumpPower->begin(LOW);
        pinMode(pwmPin, OUTPUT);
        pinMode(reverseDirectionPin, OUTPUT);

        _setSpeed(0); // Initialize pump pwm to fully off
        initialized = true;
    }

    // Placeholder for the per-loop PWM enable sequencing; currently does
    // nothing and is not called.
    //
    // While the pump was driven over PWM this had to run every few
    // milliseconds: on each power-on it held the speed line at full scale for
    // FLUIDPUMP_PWM_STARTUP_DURRATION to enable PWM control mode, then applied
    // the requested speed. The analog speed reference in use today needs no
    // such handshake, so the body is retained only as a reference for anyone
    // rewiring the pump back to PWM.
    void loopHandler()
    {
        // loop is currently disabled because we are using the analog instead of pwm control
        // -----------------------------------------------------------
        // if (!initialized)
        //     return; // Not initialized or not enabled
        // if (currentSpeedPercent == 0)
        // {
        //     timeWhenEnabled = 0;
        //     _setSpeed(0);
        //     return;
        // }
        // else if (timeWhenEnabled == 0)
        // {
        //     // Startup procedure calls for a near 100% duty cycle for a set durration on the PWM line to enable pwm control
        //     _setSpeed(100);
        //     // record when startup begins
        //     timeWhenEnabled = millis();
        //     pumpEnableComplete = false;
        //     return;
        // }
        // else if (timeWhenEnabled > FLUIDPUMP_PWM_STARTUP_DURRATION && !pumpEnableComplete)
        // {
        //     // when the pump enable time is finished, actually set the pump to the desired speed
        //     _setSpeed(abs(currentSpeedPercent));
        //     pumpEnableComplete = true;
        // }
    }

    // Returns the speed last commanded through setSpeed(), as a percentage of
    // full speed from -100 to 100, where a negative value means the pump is
    // running in reverse and 0 means it is stopped and unpowered.
    int getSpeed() const
    {
        return currentSpeedPercent;
    }

    // Sets the pump's direction and speed from a single signed percentage.
    //
    // `percent` is a fraction of full speed from -100 to 100; negative values
    // run the pump in reverse and 0 stops it and opens its power relay. Values
    // above 100 are clamped. Returns the speed actually applied, or
    // FLUID_PUMP_UNINITIALIZED if init() has not been called yet, in which
    // case nothing is driven.
    int setSpeed(int percent)
    {
        if (!initialized)
            return FLUID_PUMP_UNINITIALIZED; // Not initialized
        if (percent < -100)
            percent = -100;
        if (percent > 100)
            percent = 100;
        if (percent < 0)
        {
            runInReverseDir();
        }
        else
        {
            runInForwardDir();
        }
        currentSpeedPercent = percent;
        // loopHandler();
        _setSpeed(currentSpeedPercent);
        return currentSpeedPercent;
    }

    // Selects reverse rotation by grounding the direction line, as the pump
    // manual specifies. Takes effect on the next speed change.
    void runInReverseDir()
    {
        /// ground the pin per micropump documentation
        pinMode(reverseDirectionPin, OUTPUT);
        digitalWrite(reverseDirectionPin, LOW);
    }

    // Selects forward rotation by floating the direction line -- switching the
    // pin to an input rather than driving it high -- as the pump manual
    // specifies.
    void runInForwardDir()
    {
        /// float the pin per micropump documentation
        pinMode(reverseDirectionPin, INPUT);
    }

    // Applies the magnitude of `percent` to the speed line and switches pump
    // power to match. Internal; setSpeed() is the entry point callers use.
    //
    // The absolute value of `percent` (0 to 100) is mapped onto the 0-255
    // analog output. The power relay is opened at 0 and closed otherwise, so
    // the pump is never left powered but commanded to a standstill. Direction
    // is not touched here.
    void _setSpeed(int percent)
    {
        uint8_t pwmValue = map(abs(percent), 0, 100, 0, 255);
        if (percent == 0)
            pumpPower->turnOff();
        else
            pumpPower->turnOn();
        analogWrite(pwmPin, pwmValue);
    }
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

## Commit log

2026-06-26 serial output updates, simplified rs485 serial, moved turbo pump debug map to flash memory
2026-07-09 Switch from ArduinoLog to Debuglog library, fix int/long inconsistant usage. Use PromPlus library instead of EEPROM directly for redundancy
    [includes.h, main.cpp, modernCommands.h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]
2026-07-14 Fix accessory name in autostart sequence
    (cherry picked from commit 21a770973a170dc55483efe3f0e4534f66219eab)
    [modernCommands.h]
2026-07-15 Upload intitial fabrication documentation materials and component manuals
    [100818_v1.0.1_BOM_Std.csv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]
2026-07-21 bugfix for fluid pump rate
    [fluidpump.h]
2026-08-21 Build docs WIP Pass 1
    [BR End Cap Plate W Diaphragm Opening.dxf, BR end cap drilling guide jig bottom plate.dxf, BR end cap drilling guide jig spacer plate.dxf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]
2026-08-26 Finished Topside wiring documentation section and revised diagrams and schematics to be consistant with latest changes.
2026-09-09 Update documentation source materials and add misc ISMS testing photos
    [PyroScience AquapHOx FlowCell Attachment - Flow Cell Full.3mf]
2026-09-14 Fixes for bugs idenified by AI
    [fluidpump.h, includes.h, main.cpp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]
2026-09-14 Update documenation to reflect accurate wiring & revised code.
2026-09-16 Revised PfeifferTurboTC80 to be a standalone arduino library. Libray tests, examples and documentation added. AI Generated Changes
2026-09-18 Update pH probe fabrication documentation
    [PyroScience AquapHOx FlowCell Attachment - Flow Cell Full.3mf, PyroScience AquapHOx FlowCell Attachment - Flow Cell Full.stl]
2026-09-23 Fix LED naming to match PCB and logging CPP defines to remove extranious line numbers.
    [includes.h, main.cpp]
2026-10-06 Add housing and octopus cable potting sections
2026-10-06 Update documentaiton source materials and parts list
